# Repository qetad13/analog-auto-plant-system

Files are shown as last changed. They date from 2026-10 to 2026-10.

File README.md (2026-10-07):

# Auto Plant Grower — 센서 기반 자동 식물 재배 시스템

> 아날로그 회로 실험 및 설계 수업 Term Project · **2025.10 – 2025.12** · 5인 팀 — 3D 모델링(외관 설계) 담당, 회로 구성·실험 보조

## 프로젝트 개요

| | |
|---|---|
| **소개** | MCU 없이 **Op-Amp(LM741)와 NE555만으로** 동작하는 자동 식물 재배기. 센서 신호를 증폭·비교해 급수 펌프, 식물 조명, 물 부족 알림 LED, 환기 팬을 자동으로 제어합니다. Multisim 시뮬레이션 → 브레드보드 → PCB → 3D 프린팅 외관까지 완성했습니다. |
| **기획 의도** | 식물 생장에 꼭 필요한 **빛 · 물 · 환기**를 자동으로 관리하는 재배기를, 가정에서도 쓸 수 있게 **아날로그 부품만으로** 단순하게 만드는 것. 수업에서 배운 증폭기·비교기로 센서와 구동기를 직접 연결해, 환경에 반응하는 피드백 제어를 실제 회로로 구현하는 것이 목표였습니다. |
| **내 역할** | **외관 3D 모델링 전담** (본체 · 물탱크 · 뚜껑 · 센서/LED 마운트, Fusion 360 설계 및 출력), 브레드보드 회로 구성 · 실험 보조 |
| **기여도** | **30%** — 기구 설계 전체와 회로 구성·측정 실험 보조 (회로 설계·PCB·보고서·발표는 팀원 담당) |

## 주요 사양

| 항목 | 내용 |
|---|---|
| 입력 | YL-69 토양 습도, P5508 수위, GL5528 조도(CdS) 센서 |
| 출력 | 워터 펌프, 보라색(R+B) 식물 조명 LED, 물 부족 알림 청색 LED, 환기 팬 ×2 |
| 신호 처리 | LM741 비반전 증폭(×2) → LM741 비교기 (기준 전압 1.5 / 2.7 / 3.0 V) |
| 타이머 | NE555 비안정 모드, 팬 ON 7.6 s / OFF 6.9 s 주기 |
| 구동 | IRF520 MOSFET 모듈 ×2 (펌프 · 팬) |
| 전원 | 6 V 배터리 ×3 (±6 V), 토글 스위치 |
| 외관 | Fusion 360 설계 · 3D 프린팅 (본체 + 물탱크, 260 × 131 × 257 mm) |

<p align="center">
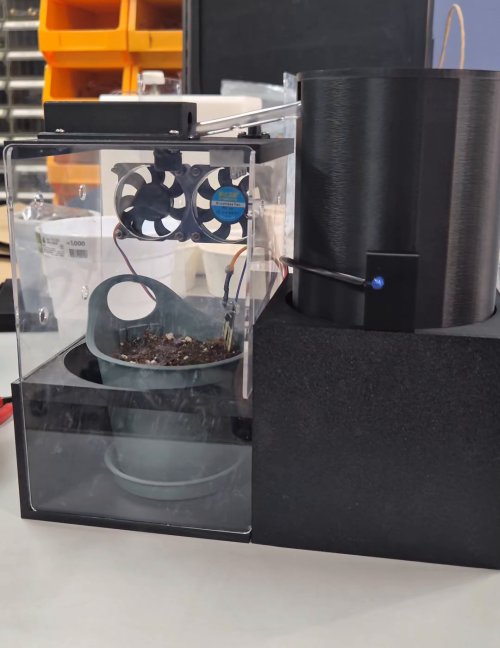
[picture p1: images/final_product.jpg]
  
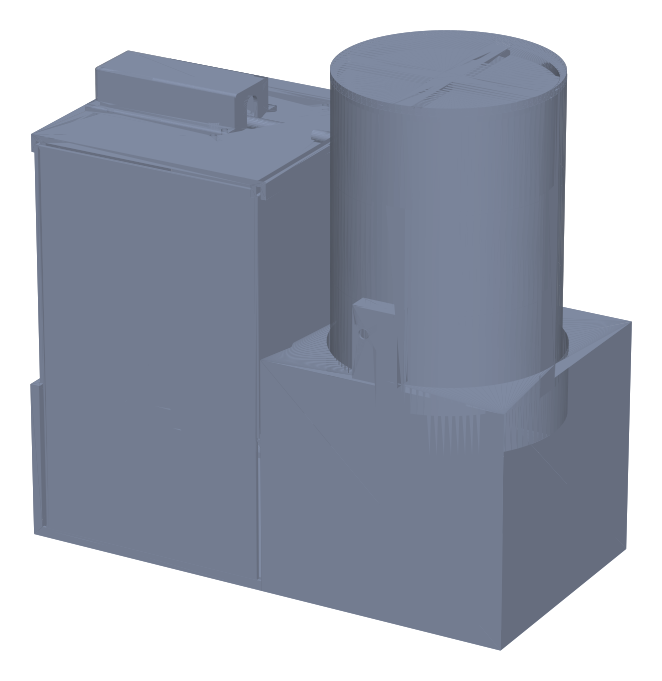
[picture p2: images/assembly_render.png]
  
  <br><sub>왼쪽 최종 완성품 · 오른쪽 전체 조립 3D 모델</sub>
</p>

---

## 시스템 구조

<p align="center">Block Diagram</p>

### 동작 원리

| 블록 | 구성 | 기준 전압 | 동작 |
|---|---|:---:|---|
| 토양 습도 | 비반전 증폭(×2) → 비교기 | 2.7 V | 건조하면 HIGH → MOSFET → 펌프 ON |
| 수위 | 비반전 증폭(×2) → 비교기 | 3.0 V | 물 부족 시 HIGH → 청색 LED ON |
| 조도 | CdS 분압 → 비교기 | 1.5 V | 밝으면 HIGH → 식물 조명 ON |
| 환기 | NE555 비안정 (R1 = 10 kΩ, R2 = 100 kΩ, C = 100 µF) | — | 주기 구형파 → MOSFET → 팬 |

```
T_H = 0.693 × (R1 + R2) × C = 0.693 × 110 kΩ × 100 µF ≈ 7.62 s
T_L = 0.693 × R2 × C        = 0.693 × 100 kΩ × 100 µF ≈ 6.93 s
```

### 제어 흐름

네 블록은 MCU 없이 각자의 아날로그 회로로 **동시에, 독립적으로** 동작합니다.

<p align="center">Flow Chart</p>

---

## 폴더 구조

```
analog-auto-plant-system/
├─ docs/                블록도 · 플로우차트 · 전체/블록별 회로도
├─ models/              3D 프린팅 STL
│  ├─ assembly.stl      전체 조립 모델
│  └─ *.stl             부품별 출력 파일 (10개)
├─ images/              시뮬레이션, PCB, 3D, 완성품 사진
│  └─ scope/            오실로스코프 측정 사진
└─ videos/              최종 동작 영상
```

---

## 하드웨어

### 회로도

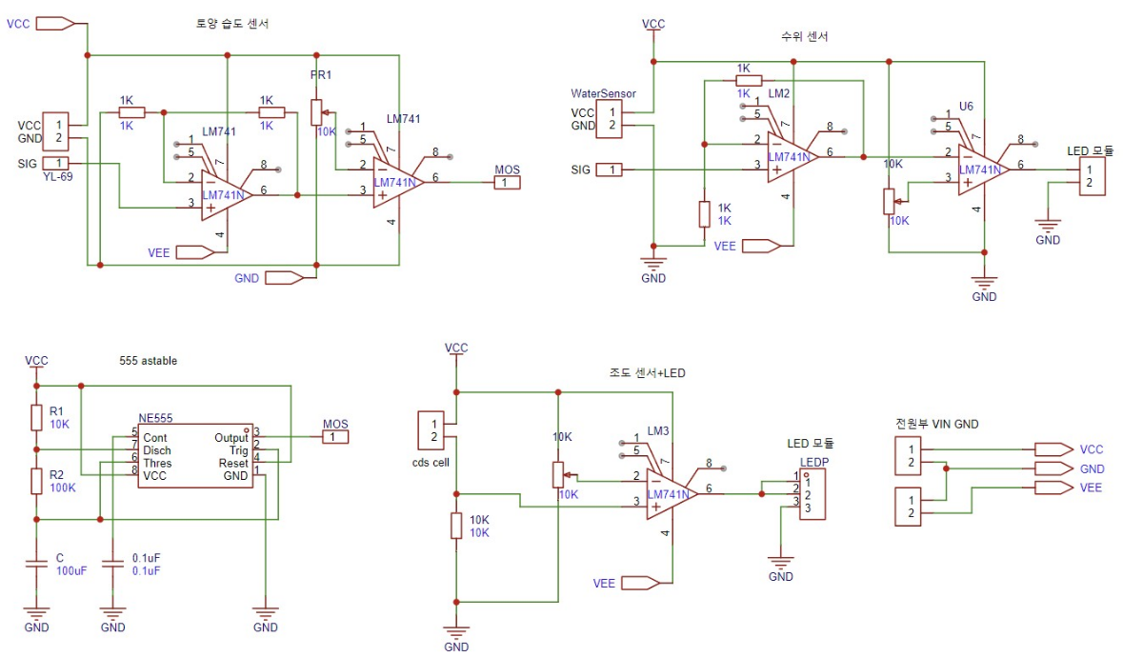
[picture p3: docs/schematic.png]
전체 회로도


블록별 회로도: [조도](docs/schematic_light.png) · [토양 습도](docs/schematic_soil.png) · [수위](docs/schematic_water.png) · [NE555 팬 제어](docs/schematic_fan.png)

### PCB

| 브레드보드 | PCB 아트워크 | PCB 완성 |
|:---:|:---:|:---:|
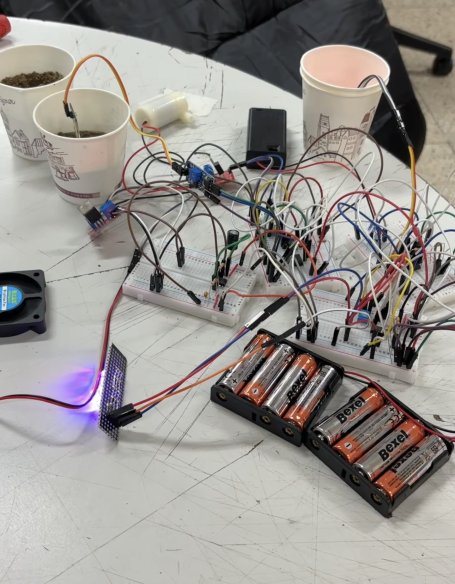
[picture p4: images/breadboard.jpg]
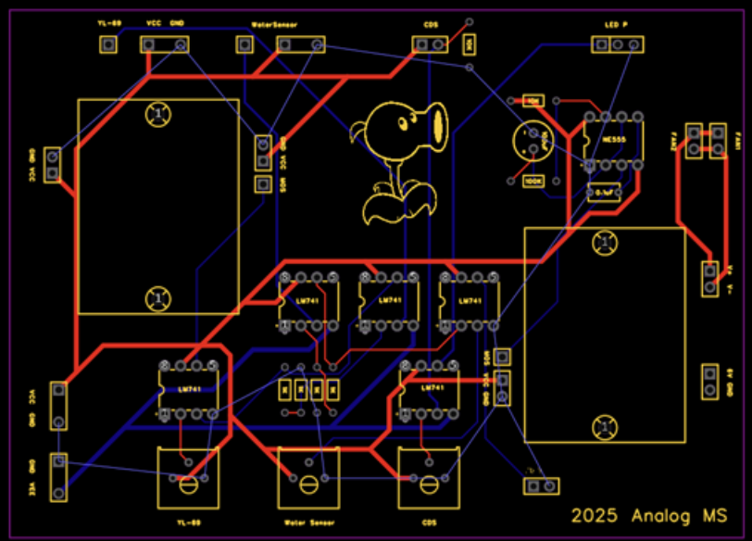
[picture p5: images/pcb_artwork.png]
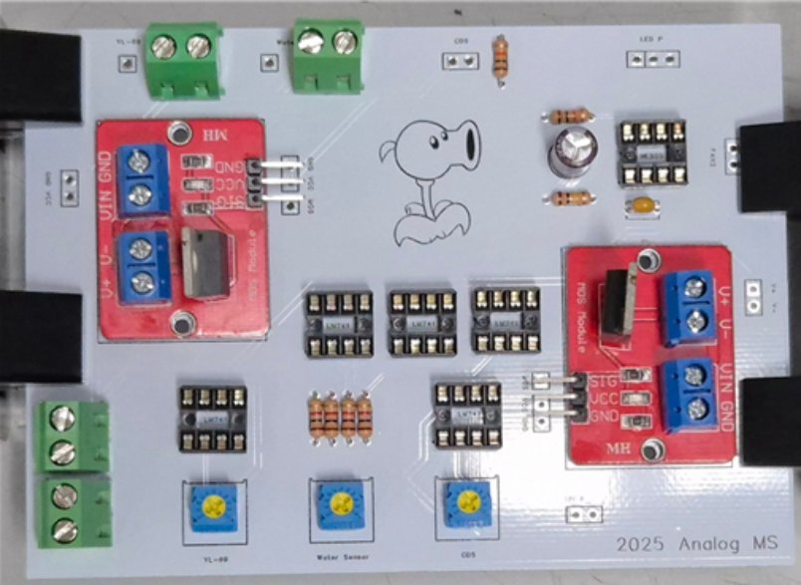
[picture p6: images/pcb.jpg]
|  |  |  |

### 기구부 (3D 모델링 — 담당)

Fusion 360으로 외관을 설계하고 3D 프린팅했습니다. STL 파일은 GitHub에서 클릭하면 3D로 바로 볼 수 있습니다.

| 파일 | 부품 | 크기 (mm) |
|---|---|---|
| [`assembly.stl`](models/assembly.stl) | **전체 조립 모델** | 260 × 131 × 257 |
| [`main_base.stl`](models/main_base.stl) | 본체 하우징 | 130 × 130 × 120 |
| [`plant_pot.stl`](models/plant_pot.stl) | 화분 받침 | 140 × 130 × 80 |
| [`main_lid.stl`](models/main_lid.stl) | 본체 뚜껑 | 130 × 126 × 9 |
| [`main_lid_ldr_mount.stl`](models/main_lid_ldr_mount.stl) | 조도 센서 마운트 | 20 × 20 × 10 |
| [`main_lid_hose_cover.stl`](models/main_lid_hose_cover.stl) | 펌프 호스 덮개 | 80 × 46 × 20 |
| [`water_tank.stl`](models/water_tank.stl) | 물탱크 | 109 × 109 × 150 |
| [`water_tank_lid.stl`](models/water_tank_lid.stl) | 물탱크 뚜껑 | 110 × 110 × 8 |
| [`grow_led_holder.stl`](models/grow_led_holder.stl) | 조명 LED 홀더 | 65 × 21 × 7 |
| [`grow_led_cover.stl`](models/grow_led_cover.stl) | 조명 LED 덮개 (접착 고정) | 46 × 21 × 1 |
| [`water_level_led_holder.stl`](models/water_level_led_holder.stl) | 물 부족 표시 LED 케이스 | 24 × 37 × 10 |

- 본체(화분·회로 수납)와 원통형 물탱크를 나란히 배치하고, 펌프 호스는 뚜껑의 호스 덮개로 정리
- 조도 센서는 본체 뚜껑 위 전용 마운트에 고정해 주변 광량을 받도록 배치
- 물탱크 뚜껑은 출력·결합 테스트를 거쳐 3차 수정본까지 개선

### 부품

| 부품 | 규격 | 수량 |
|---|---|:---:|
| Op-Amp | LM741 | 5 |
| 타이머 IC | NE555 | 1 |
| 센서 | YL-69 (토양 습도), P5508 (수위), GL5528 (조도) | 각 1 |
| MOSFET 모듈 | IRF520 | 2 |
| 워터 펌프 / 팬 모터 | 3–5 V 130–240 mA / 5 V 140 mA | 1 / 2 |
| LED | 청색 1, RGB 4핀 4 | 5 |
| 저항 / 가변저항 | 330 Ω ×5, 1 kΩ ×4, 10 kΩ ×2, 100 kΩ ×1 / 10 kΩ ×3 | 15 |
| 커패시터 | 0.1 µF 세라믹, 100 µF 전해 | 각 1 |
| 전원 / 스위치 | 6 V 배터리 / MTS-203 토글 | 3 / 1 |

---

## 결과

### 시뮬레이션 (Multisim)

| 조도 센서부 | 수위 센서부 | NE555 팬 제어부 |
|:---:|:---:|:---:|
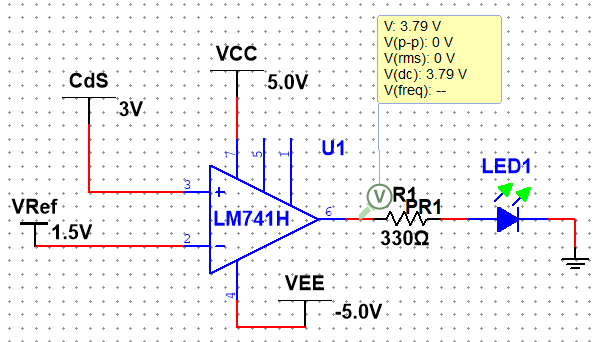
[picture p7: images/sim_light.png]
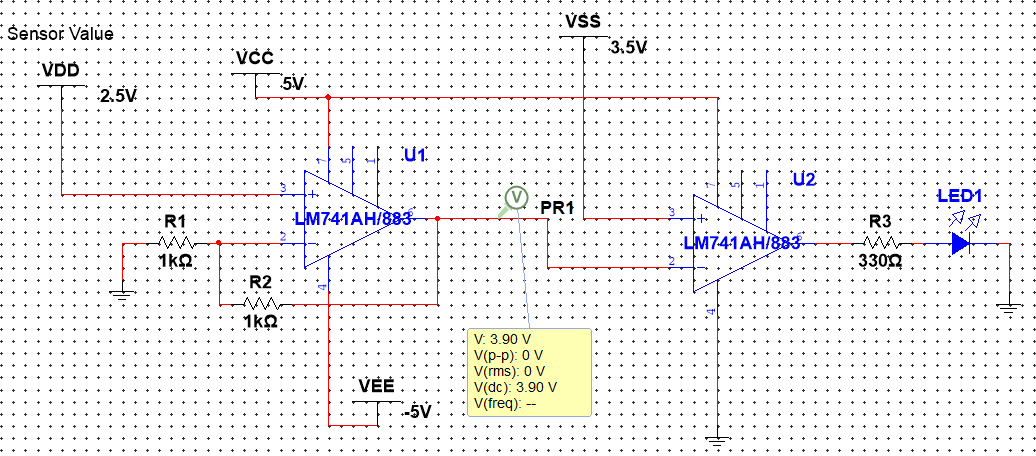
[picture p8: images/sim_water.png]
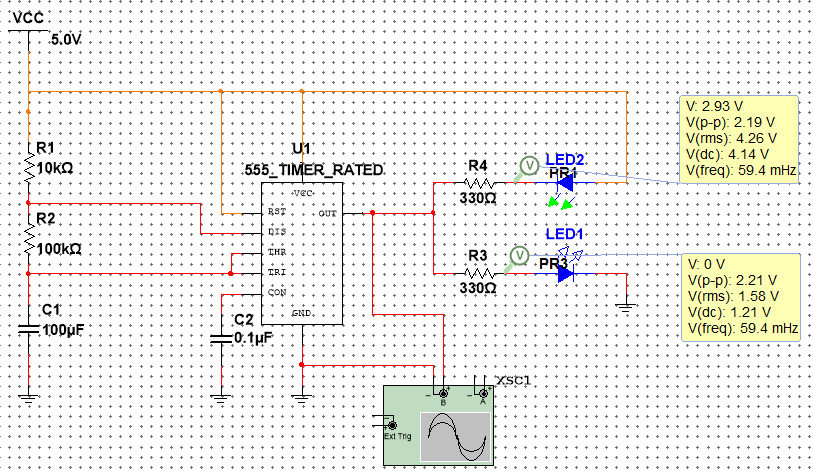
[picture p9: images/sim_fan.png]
|  |  |  |

NE555 주기: 이론 T<sub>H</sub> 7.623 s / T<sub>L</sub> 6.93 s → 시뮬레이션 **7.615 s / 6.992 s**

### 오실로스코프 측정 (CH1: 기준 전압, CH2: 센서 출력)

| 조도: 밝을 때 / 어두울 때 | 토양: 건조 / 습함 | 수위: 부족 / 충분 |
|:---:|:---:|:---:|
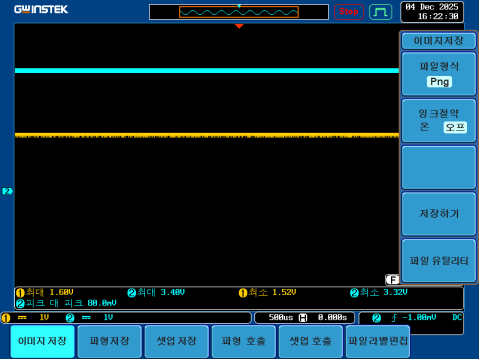
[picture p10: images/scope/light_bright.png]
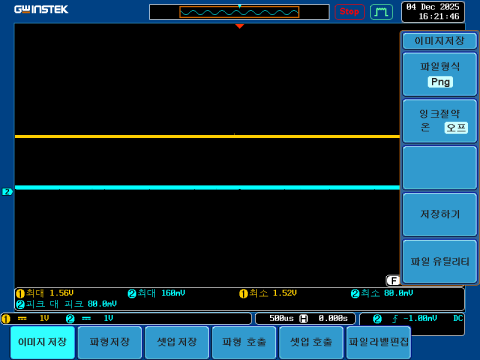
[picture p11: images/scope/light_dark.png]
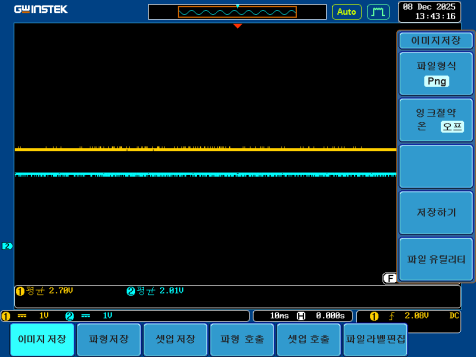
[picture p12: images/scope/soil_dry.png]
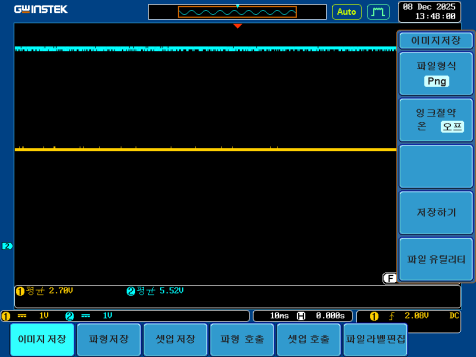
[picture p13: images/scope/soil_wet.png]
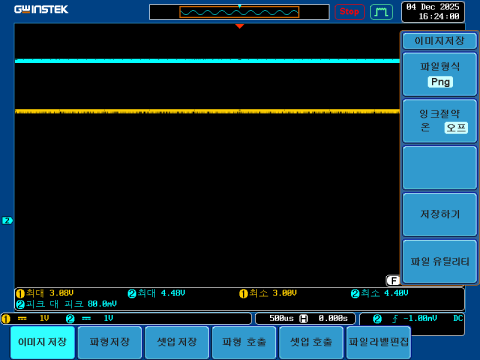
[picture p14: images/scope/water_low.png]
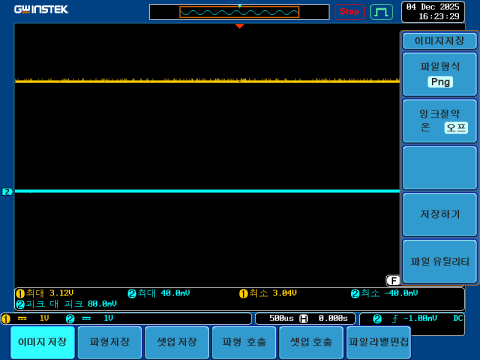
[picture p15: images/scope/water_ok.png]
| <br> | <br> | <br> |
| 3.4 V / 약 0 V (기준 1.5 V) | 5.5 V / 2 V (기준 2.7 V) | 약 0 V / 4.4 V (기준 3 V) |

| 비반전 증폭 ×2 (1.5 V → 3 V) | NE555 출력 주기 |
|:---:|:---:|
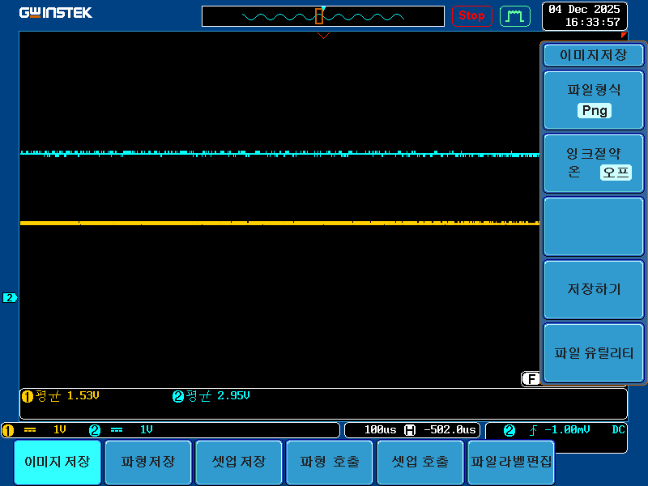
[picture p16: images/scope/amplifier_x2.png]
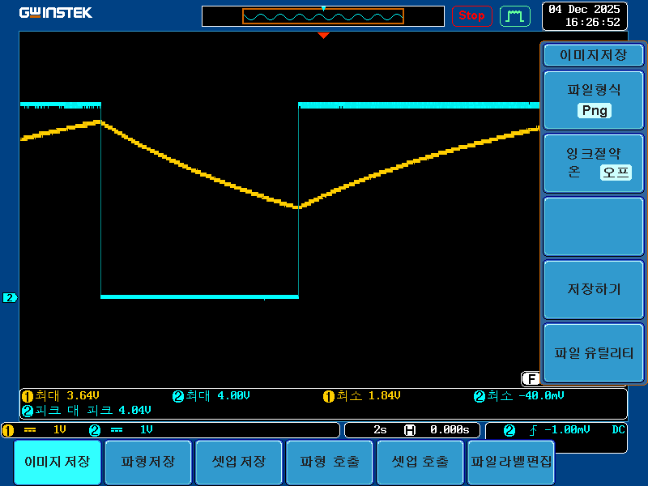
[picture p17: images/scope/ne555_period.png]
|  |  |

동작 영상: [`videos/final_demo.mp4`](videos/final_demo.mp4)

---

## 내 담당 범위

5인 팀 프로젝트에서 제가 담당한 부분입니다.

| 파트 | 내용 |
|---|---|
| 기구 | 본체 · 화분 받침 · 물탱크 · 뚜껑 · 센서/LED 마운트 등 외관 전체 3D 모델링 및 출력 (Fusion 360) |
| 회로 | 브레드보드 회로 구성 |
| 실험 | 센서 출력 측정, 오실로스코프 실험 보조 |

---

## 트러블슈팅

### 1. 센서 데이터시트 부재
- **증상**: 토양 습도·수위 센서의 출력 특성을 알 수 없어 비교기 기준 전압을 정할 수 없음
- **해결**: 실제 흙(건조/습함)과 물(부족/충분) 조건에서 출력 전압을 직접 측정하고, 가변저항으로 기준 전압을 맞춤

### 2. 센서 출력 변화 폭이 작음
- **증상**: 상태가 바뀌어도 센서 출력 차이가 작아 비교기 판정이 경계에서 불안정
- **해결**: 비반전 증폭기로 2배 증폭한 뒤 비교 → 상태별 전압 차가 커져 히스테리시스 회로 없이도 판정이 안정됨

### 3. 다채널 Op-Amp(LM324) 출력 불량
- **증상**: 소자 수를 줄이려 LM324를 썼지만 원하는 출력이 나오지 않음
- **원인**: ±15 V가 아닌 ±6 V 배터리 전원에서 LM741과 소자 특성이 달라진 것으로 추정
- **해결**: 수업에서 검증한 LM741로 통일 (블록당 1개씩, 총 5개)

### 4. 6 V 전원으로 모터·펌프 직접 구동 불가
- **증상**: 비교기·NE555 출력만으로는 팬과 펌프를 돌릴 전류가 부족
- **해결**: IRF520 MOSFET 모듈을 스위치로 사용해 제어 신호와 구동 전원을 분리

### 5. 조명 제어 방식의 한계 (개선 과제)
- 처음엔 NE555로 조명 주기를 만들려 했지만 주기가 길어질수록 오차가 커져 조도 센서 방식으로 변경
- 현재는 센서가 가려지면 조명이 꺼지는 한계가 있고, NE555 주기도 고정저항이라 조절 불가 → 가변저항 · 다른 제어 방식으로 개선 가능

---

## 실행 방법

### 1. 기구 출력
- `models/*.stl`을 슬라이서에서 열어 3D 프린터로 출력 (`assembly.stl`은 조립 확인용)
- `grow_led_cover.stl`은 출력 후 LED 홀더에 접착제로 고정

### 2. 동작
- 토글 스위치로 전원 ON → 네 블록이 센서 값에 따라 자동 동작
- 기준 전압은 각 비교기 옆 10 kΩ 가변저항으로 환경에 맞게 조정

---

## 기술 스택
`NI Multisim` · `Fusion 360` `3D 프린팅`

## 라이선스 / 출처
- 회로 및 기구 설계는 팀에서 직접 작성했으며, 블록도·플로우차트는 결과보고서를 바탕으로 다시 그렸습니다.
- 참고: [YL-69 Soil Moisture Sensor Guide](https://randomnerdtutorials.com/guide-for-soil-moisture-sensor-yl-69-or-hl-69-with-the-arduino/) · [LM741 Datasheet](https://www.alldatasheet.com/html-pdf/840177/TI1/LM741/226/4/LM741.html) · [555 Astable Mode](https://www.electronics-tutorials.ws/waveforms/555_oscillator.html) · [GL5528 Datasheet](https://www.alldatasheet.com/html-pdf/1131893/ETC2/GL5528/227/2/GL5528.html)

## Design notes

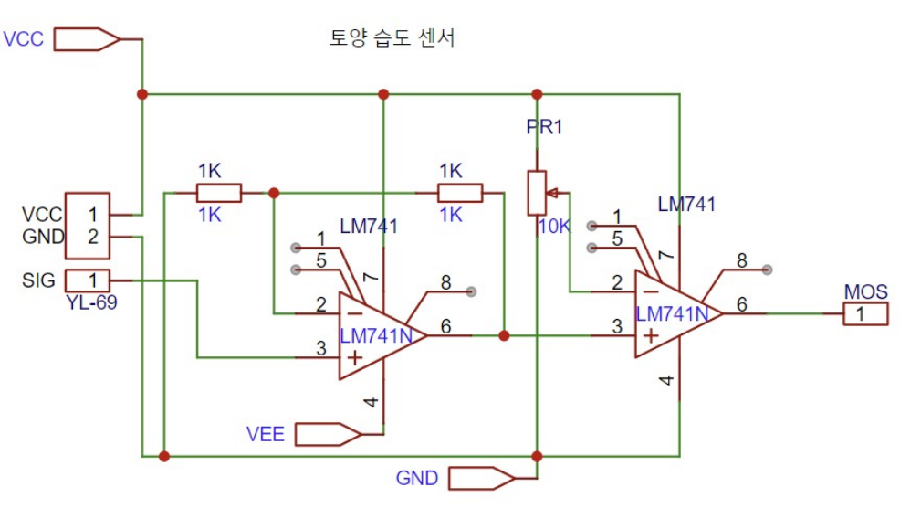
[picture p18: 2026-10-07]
docs/schematic_soil.png

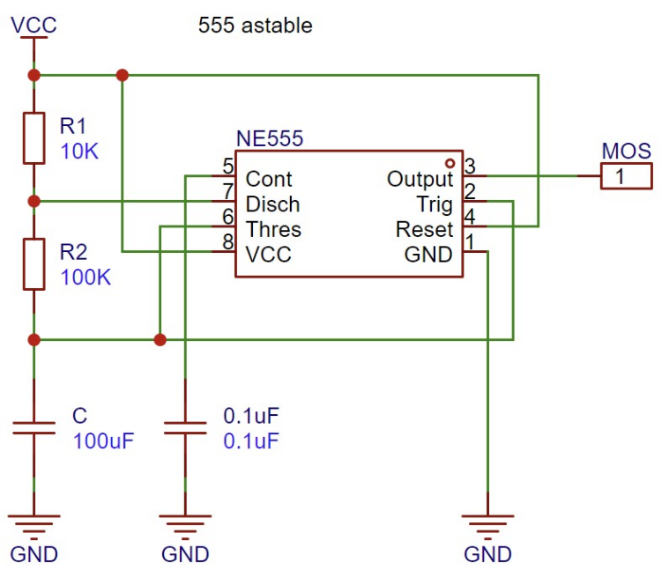
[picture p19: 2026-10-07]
docs/schematic_fan.png

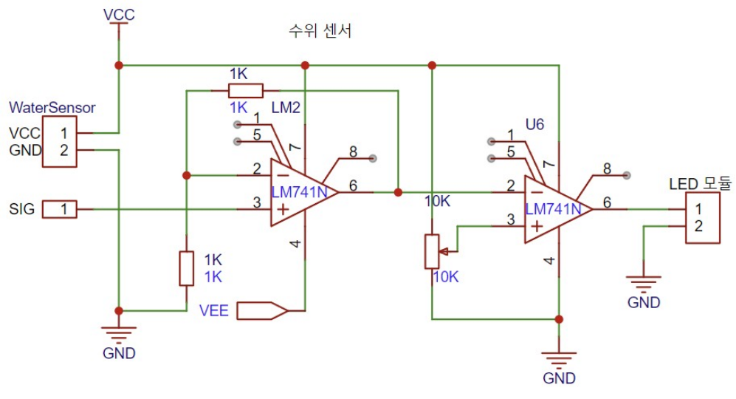
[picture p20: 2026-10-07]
docs/schematic_water.png

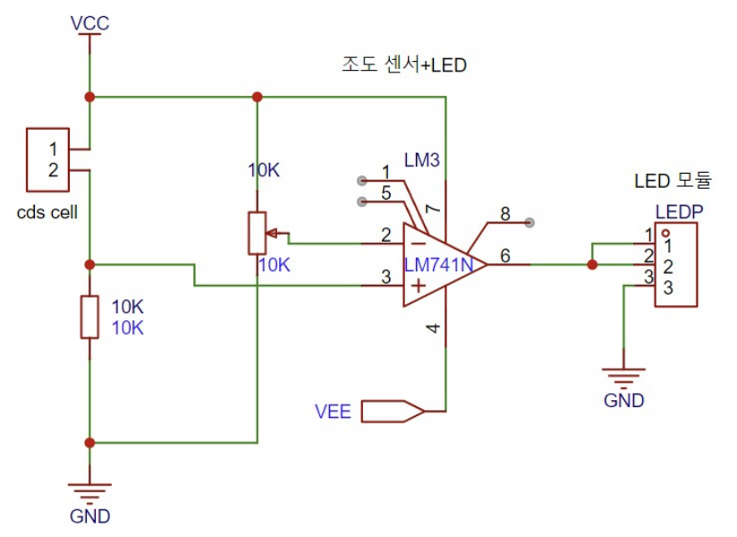
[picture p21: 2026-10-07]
docs/schematic_light.png

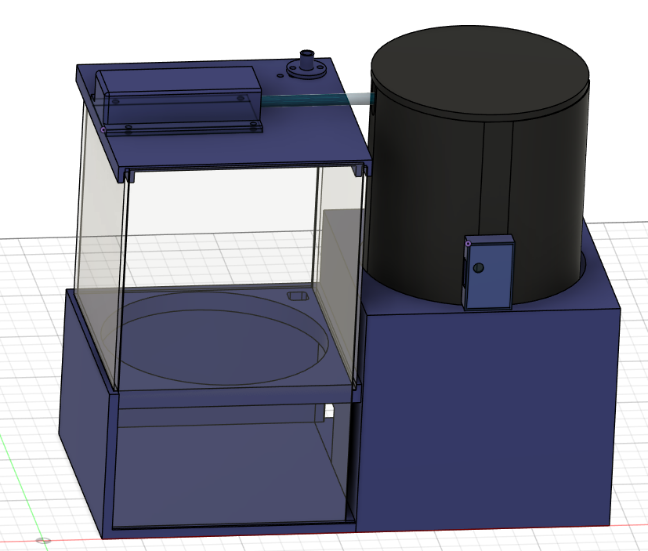
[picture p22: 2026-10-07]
images/3d_model.png

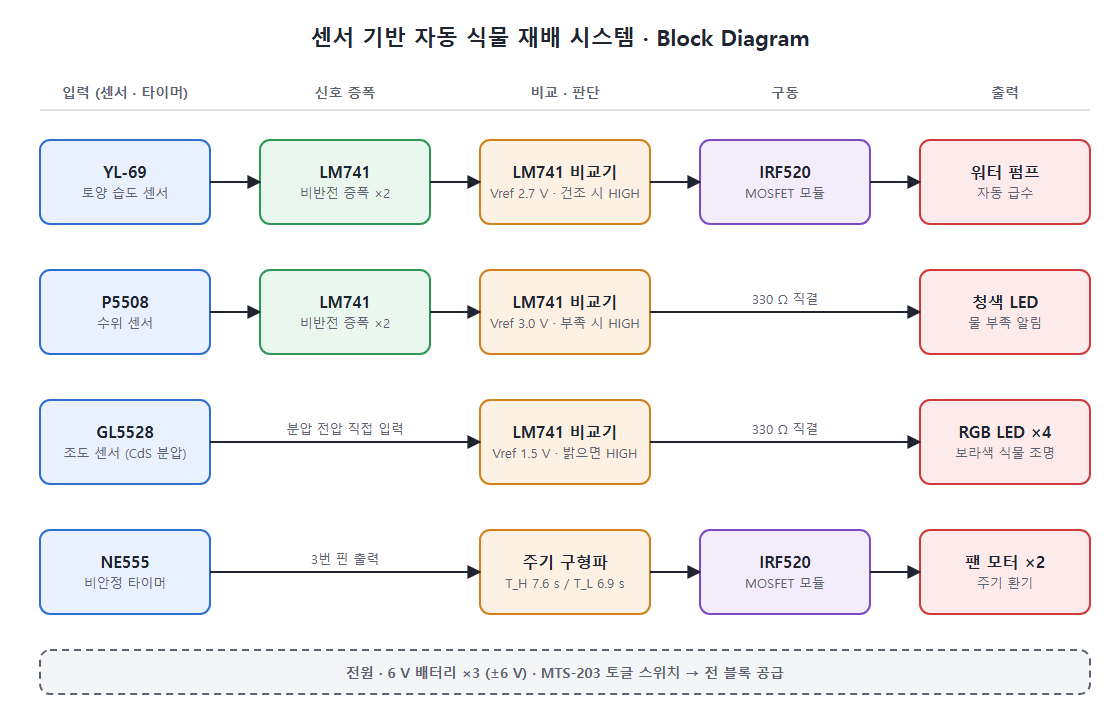
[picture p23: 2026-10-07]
docs/block_diagram.png

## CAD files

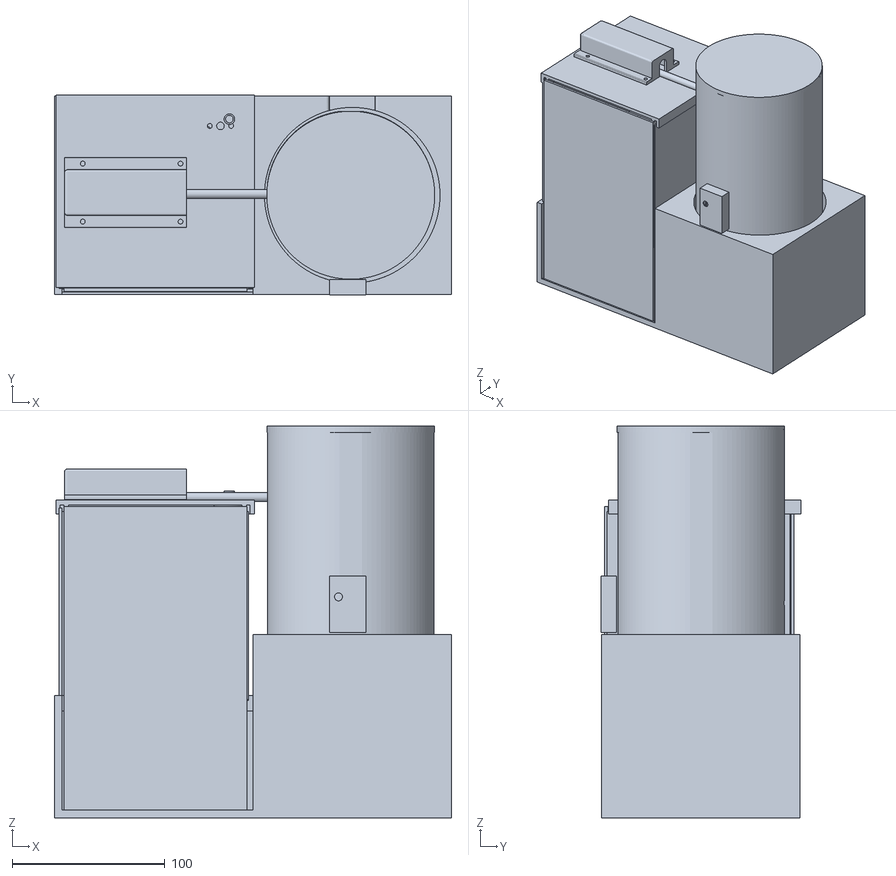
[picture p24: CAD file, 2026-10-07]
models/assembly.stl
260.0 x 130.8 x 256.5

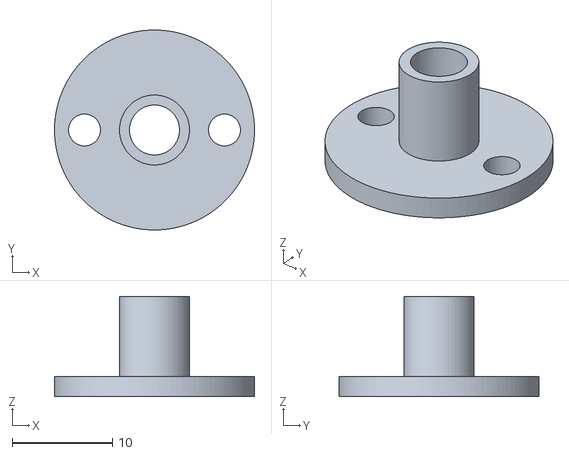
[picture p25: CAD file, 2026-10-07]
models/main_lid_ldr_mount.stl
20.0 x 20.0 x 10.0

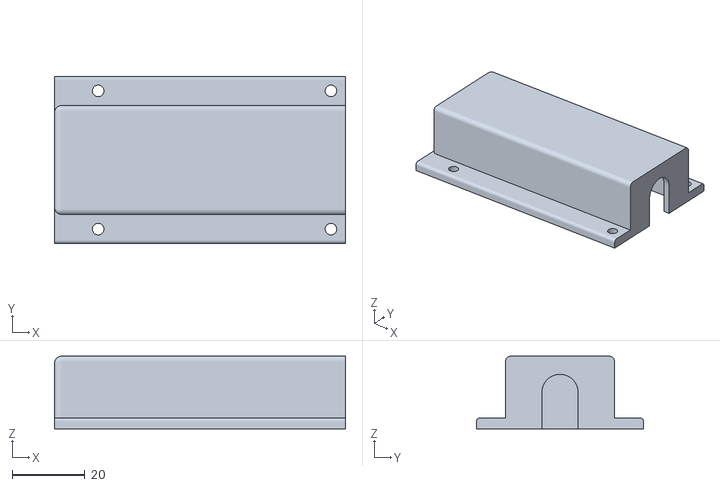
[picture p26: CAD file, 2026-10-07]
models/main_lid_hose_cover.stl
80.0 x 46.0 x 20.0

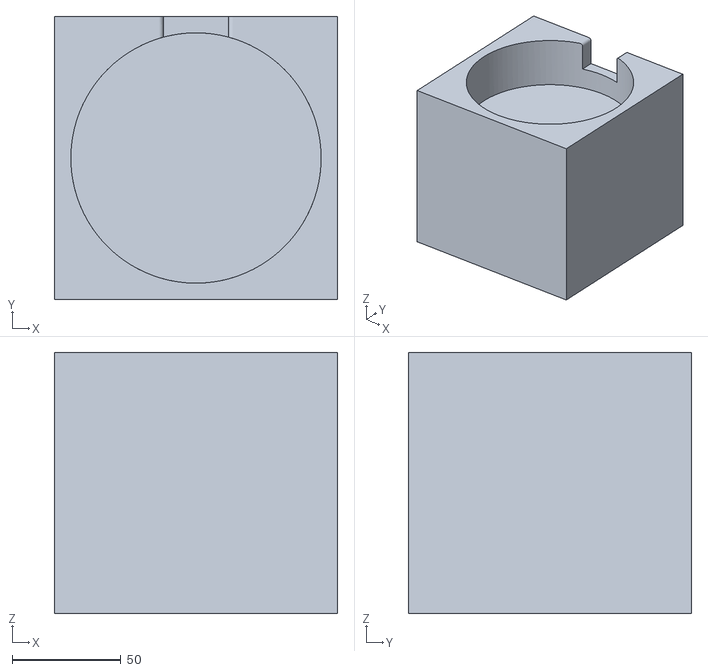
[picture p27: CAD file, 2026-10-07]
models/main_base.stl
130.0 x 130.0 x 120.0

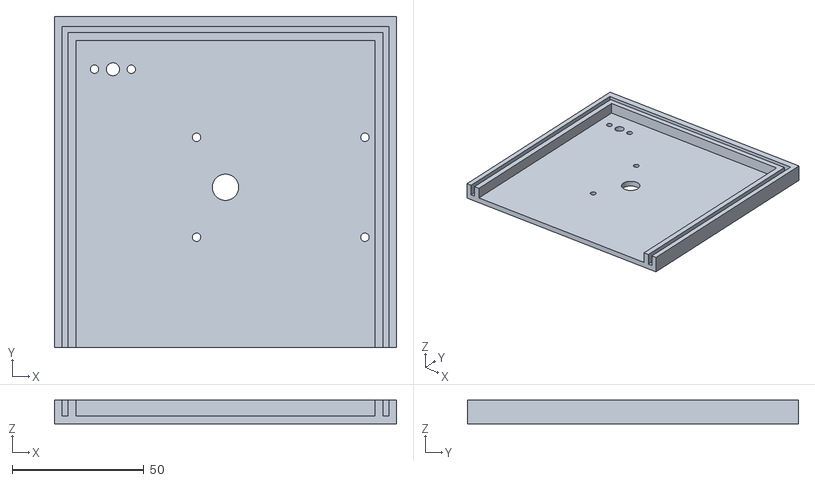
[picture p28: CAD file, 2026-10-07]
models/main_lid.stl
130.0 x 126.0 x 9.00

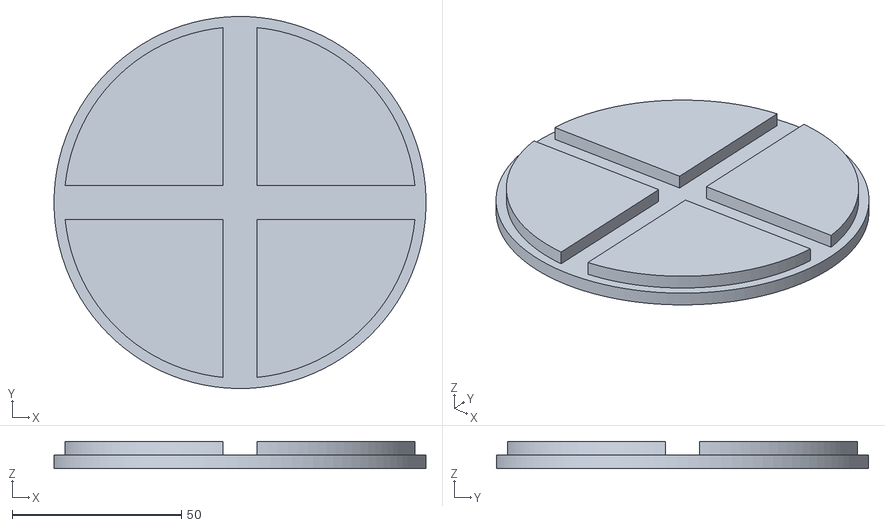
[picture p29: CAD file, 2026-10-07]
models/water_tank_lid.stl
110.0 x 110.0 x 8.00

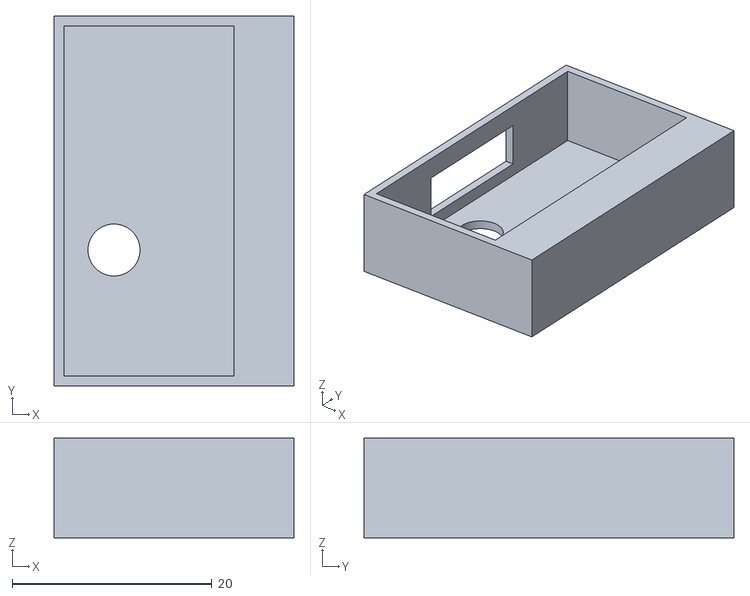
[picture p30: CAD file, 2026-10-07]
models/water_level_led_holder.stl
24.0 x 37.0 x 10.0

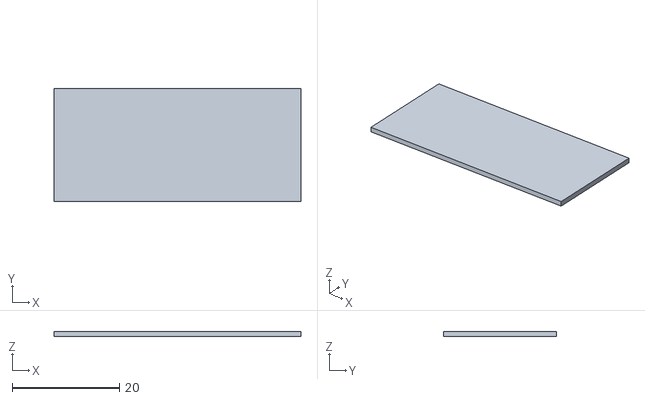
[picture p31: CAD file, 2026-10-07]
models/grow_led_cover.stl
46.0 x 21.0 x 1.00

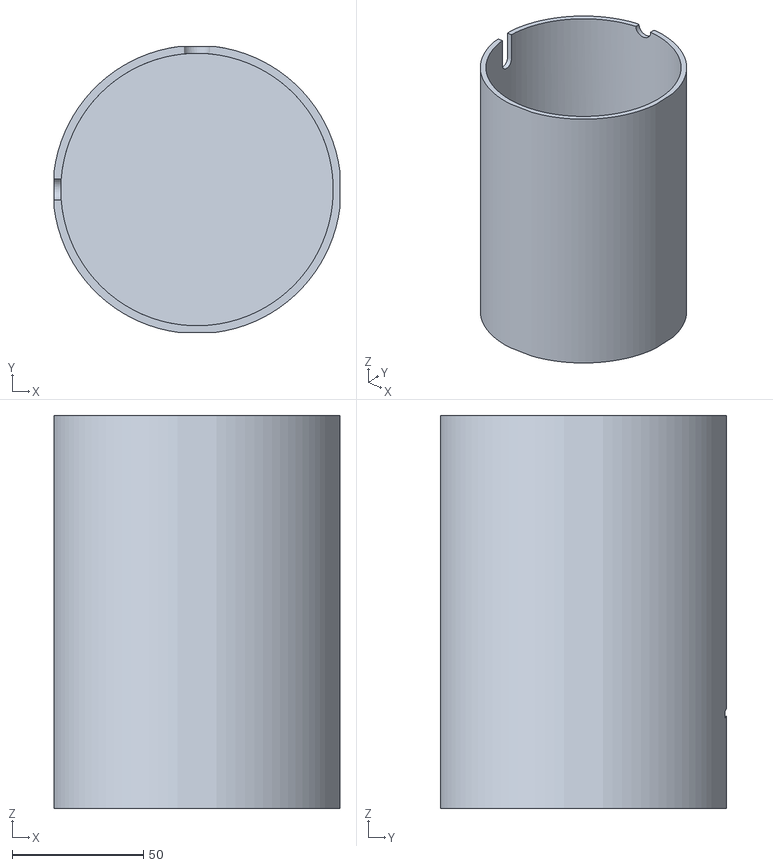
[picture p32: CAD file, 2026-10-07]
models/water_tank.stl
109.0 x 109.0 x 150.0

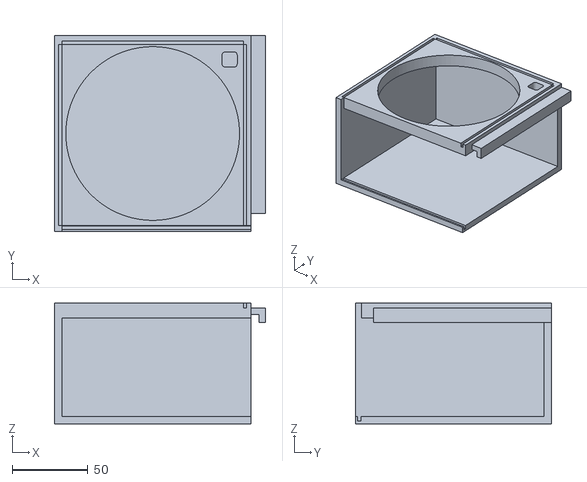
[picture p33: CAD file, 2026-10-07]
models/plant_pot.stl
139.7 x 130.0 x 80.0

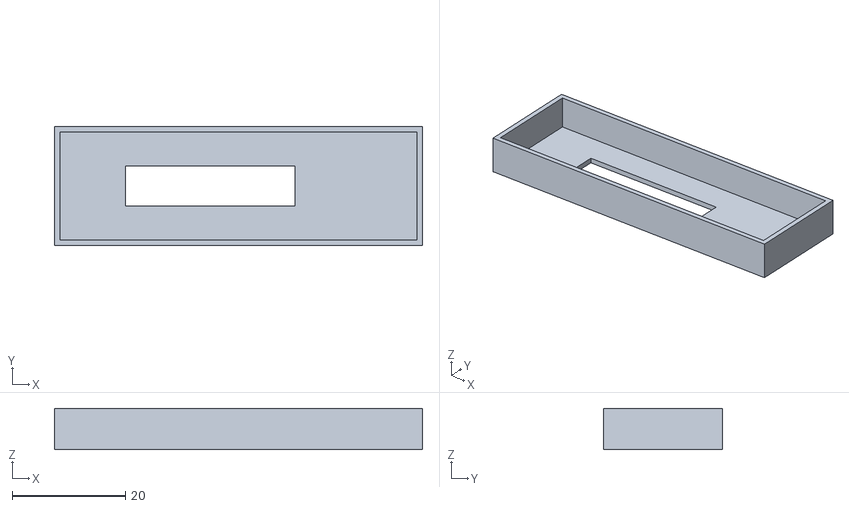
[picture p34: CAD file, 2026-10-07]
models/grow_led_holder.stl
65.0 x 21.0 x 7.30

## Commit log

2026-10-07 Add sensor-based automatic plant growing system (analog term project)
    Op-Amp/NE555 circuit docs, simulation and oscilloscope results,
    PCB photos, final 3D-printed enclosure STL models, and demo video.
    [grow_led_cover.stl, grow_led_holder.stl, main_base.stl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]
2026-10-07 Redraw block diagram and flow chart, add assembly model
    [assembly.stl]
2026-10-07 Add assembly render image
2026-10-23 동작 영상 썸네일 및 라이선스 추가
